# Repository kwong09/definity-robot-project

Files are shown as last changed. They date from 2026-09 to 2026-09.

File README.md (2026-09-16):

# definity-robot-project
## Project Description
A robot that navigates through a challenging obstacle course and can intake and shoot tennis balls. This project focuses on the frame of the robot and the intake subsystem (the rest of the team members worked on other parts of the robot!)

## Features:
* Intake system that can hold up to 8 tennis balls
* Robot frame with rotating front as suspension
* Drivebase that can run over cinderblocks and bricks

## CAD Model:
This is the full assembly of the robot with the intake subsystem attached.
The intake subsystem was tightened using M4 or M3 screws (either worked for the 3d printed shaft collars).
The Maxynos motors were attached to the frame of the robot using M3 screws.
The frame for the intake was made of Aluminum 6061 and was bent in the machine shop (drawings for the intake subsystem and frame for the robot are attached in the repository).  

When assembling the intake, start from the side that does not have the motor. Make sure to also add the belts on before pushing it through the bearing. That way, you are able to daisy chain the belts so that it alternates. Preview the picture of the actual assembly at the bottom of this readme file to see how you must orient the belts.



## More Photos and Videos!!
https://github.com/user-attachments/assets/d4b2ccb0-fa03-435b-ad92-068b4372a665



## Important Links
 - [Onshape document](https://cad.onshape.com/documents/242f1b4dc737510c4a5df910/w/1bdbd6909af1f2f738e34575/e/52617dcb231c25f66da39c03) *(this includes all the 3D print files as well as full robot assembly)*
 - [Parts list](https://docs.google.com/spreadsheets/d/1HUPfm7-IXxoTsjJXf8ZeQtVRJgV2OwNiN3OtU4khO2M/edit?usp=sharing) *(this has all of the parts that we bought off Amazon, AndyMark, etc. for any components we did not manufacture ourselves)*

## Bill of Materials (COTS Parts)
| Item | Link | Cost | Quantity | Total Cost | Notes |
| --- | --- | --- | --- | --- | --- |
| Motors | [Amazon.com: Maxynos Thor 2826 Planetary Gear Brushless Motor (Outrunner), DC 15 V, 3.7 N·m (37.7 kg·cm) Torque, 28 mm Gearbox, 6 mm Shaft, for Robotics, Automation, and RC Applications (1000KV, Gear Ratio 19:1) : Industrial & Scientific](https://www.amazon.com/dp/B0FL7X27B4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) | $57.99 | 5 | $289.95 | |
| ESC | [Amazon.com: 30A Electric Brushless Motor Controller, 2 Pcs ESC Speed Controller with XT60 and 3.5mm Bullet Plugs for RC Drone RC Airplane Helicopter (30A) : Toys & Games](https://www.amazon.com/Electric-Brushless-Controller-Airplane-Helicopter/dp/B0CZNM4H7H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) | $18.59 | 2 | $37.18 | not using anymore (unidirectional) |
| Wheel Rubber | [Amazon.com: TORRAMI Solid Neoprene Rubber Strips Roll 1/8 (.125) inch Thick X 2 inch Wide X 10 Feet, for DIY Weather Stripping, Gasket, Seal : Industrial & Scientific](https://www.amazon.com/Neoprene-Rubber-Strips-Weather-Stripping/dp/B0859FZR2S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) | $14.38 | 1 | $14.38 | |
| Battery | Other Team | $40.00 | 2 | $80.00 | |
| Charger | Other Team | $60.00 | 1 | $60.00 | |
| Screws | [https://www.amazon.com/smseace-Assortment-Machinery-Automotive-Motorcycle/dp/B0DN1676NW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](https://www.amazon.com/smseace-Assortment-Machinery-Automotive-Motorcycle/dp/B0DN1676NW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) | $7.99  | 1 | $7.99 | |
| Pillow bearings | [pson 2Pcs 25mm Bore Mounted Pillow Block Bearing KP000, Self‑Aligning Zinc Aluminum Alloy Housing for Linear Shaft Rods, Machinery: Amazon.com: Industrial & Scientific](https://www.amazon.com/pson-Mounted-Self%E2%80%91Aligning-Aluminum-Machinery/dp/B0G4D36Z1X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) | $6.69  | 1 | $6.69 | |
| Front Rotation Shaft | [McMaster-Carr](https://www.mcmaster.com/products/4138n85/) | $15.64 | 1 | $15.64 | |
| Front Rotation Collars | [McMaster-Carr](https://www.mcmaster.com/products/6056n18/) | $2.00  | 2 | $4.00 | |
| 1/8" Rivets | [McMaster-Carr](https://www.mcmaster.com/products/97447a020/) | $10.57 | 1 | $10.57 | |
| XT60 Power Distribution | [Amazon.com: XT60 to 4 Channel XT60 Plug Power Distribution Board Optional Base Shell for Robot RC Boat Submarine DIY Parts : Toys & Games](https://www.amazon.com/Channel-Power-Distribution-Optional-Submarine/dp/B0FQTJSRVB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) | $15.99 | 1 | $15.99 | |
| Rubber Glue | [https://www.amazon.com/dp/B0DLKMS6LR?niid=nl_cl_lst_a_1_0&ref_=nl_cl_lst_a_1_0&nrid=17TS82XMNZMFRY1FD6C7&th=1](https://www.amazon.com/dp/B0DLKMS6LR?niid=nl_cl_lst_a_1_0&ref_=nl_cl_lst_a_1_0&nrid=17TS82XMNZMFRY1FD6C7&th=1) | $7.99  | 1 | $7.99 | |
| ESC | [https://www.amazon.com/Maxynos-Bidirectional-Controller-Connector-Underwater/dp/B0FPWNBR88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](https://www.amazon.com/Maxynos-Bidirectional-Controller-Connector-Underwater/dp/B0FPWNBR88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) | $28.99 | 4 | $115.96 | bidirectional replacements |
| Double Sided Tape | [Amazon.com: tapify Double Sided Tape Heavy Duty 0.39 x 10FT \| Double Sided mounting Tape for Walls,vhb Strong for Car, LED Strip Light, Home/Office Decorr : Office Products](https://www.amazon.com/dp/B0CPX8HFNZ?psc=1&smid=A2Z15M95UG8Y2&ref_=chk_typ_imgToDp) | $6.99  | 1 | $6.99 | |
| EC3 to XT60 adapter | [Amazon.com: Laisomeke XT60 to EC3 Male Female Adapter Connector with 5CM Cable for RC FPV Drone Car Lipo NiMH Battery Charger ESC (4 Pack) : Toys & Games](https://www.amazon.com/gp/product/B0BY8RH35S/ref=ox_sc_act_title_2?smid=A16DPPR9USB1X5&psc=1) | $8.59  | 0.5 | $4.30 | |
| Wheel Hubs | [4Pcs 6mm Flange Coupling Connector, Rigid Guide Model Coupler Accessory, Shaft Axis Fittings for DIY RC Model Motors: Amazon.com: Industrial & Scientific](https://www.amazon.com/dp/B08334N261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) | $7.95  | 1 | $7.95 | |
| Buck Boosters | [Amazon.com: PlusRoc Waterproof 12V/24V to 5V 5A Step Down Converter, 25W DC-DC Buck Converter with Open Wires for DIY Electronics Projects (2-Pack) : Electronics](https://www.amazon.com/dp/B0FYNCSV2Z?psc=1&smid=A16MBAJLOTGB84&ref_=chk_typ_imgToDp) | $12.99 | 1 | $12.99 | |
| Pneumatic Wheels | [https://wcproducts.com/collections/wheels-hubs/products/pneumatic-wheels](https://wcproducts.com/collections/wheels-hubs/products/pneumatic-wheels) | $14.99 | 4 | $59.96 | Pneumatic Wheel Tire (8" OD, SmoothGrip) (WCP-0158) |
| IMU | [https://www.amazon.com/dp/B0CL26J81F](https://www.amazon.com/dp/B0CL26J81F) | $20.99 | 1 | $20.99 | |
| 12V Regulator | [https://www.amazon.com/dp/B07KWX33X5?niid=nl_cl_lst_a_1_2&ref_=nl_cl_lst_a_1_2&nrid=EKRBPCA692ZRFPZ2Z127&th=1](https://www.amazon.com/dp/B07KWX33X5?niid=nl_cl_lst_a_1_2&ref_=nl_cl_lst_a_1_2&nrid=EKRBPCA692ZRFPZ2Z127&th=1) | $14.99 | 1 | $14.99 | |
| 1/2" Hex Bearing | [https://www.amazon.com/XiKe-Bearing-Wheelbarrows-Suitable-Replacement/dp/B01MF5A4GF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](https://www.amazon.com/XiKe-Bearing-Wheelbarrows-Suitable-Replacement/dp/B01MF5A4GF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) | $14.99 | 2 | $29.98 | |
| 1/2" Hex Shaft | [https://www.mcmaster.com/9063T31-9063T313/](https://www.mcmaster.com/9063T31-9063T313/) | $15.38 | 2 | $30.76 | |
| Higher Quality Hubs | [Amazon.com: MORFUM 4Pcs Black 6mm Flange Coupling Connector, Aluminum Alloy Rigid Flange Coupling Motor Guide Shaft Coupler Shaft Axis Fittings Universal Aluminum Mounting Hub for 6mm Shaft : Industrial & Scientific](https://www.amazon.com/gp/product/B0FJ8DP4BY/ref=ox_sc_act_image_2?smid=A1Q5NIBUBLYOMT&psc=1) | $10.99 | 1 | $10.99 | |
| Pivot Motor Test | [Amazon.com: Copkim 6 Pack 12v DC Worm Gear Motor Turbine Electric Gear Box Motor with 8mm Flange Coupling Connector Rigid Flange Coupling and 370 Mounting Bracket with Screw for DIY Projects(12V 16rpm) : Industrial & Scientific](https://www.amazon.com/Copkim-Electric-Coupling-Connector-Mounting/dp/B0G2BNVRV7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) | $27.99 | 3 | $83.97 | |
| Flywheel motors | [Amazon.com: FairySandy 4 Pack 12V-24V 775 DC Electric Motor and GT2 Synchronous Wheel Aluminum Timing Pulley and DC Motor Speed Controller Driver Control Module for Milling Machine Electric Drill(D-Shaped Shaft) : Toys & Games](https://www.amazon.com/FairySandy-Electric-Synchronous-Aluminum-Controller/dp/B0FYFWTY6M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) | $16.99 | 2 | $33.98 | |
| Belt | [https://www.amazon.com/dp/B0FRDL4X1Z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](https://www.amazon.com/dp/B0FRDL4X1Z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) | $7.69  | 2 | $15.38 | 200mm L, 6mm W |
| PWM Relay Module | [https://www.amazon.com/ZORZA-Controller-Spotlight-Electronic-Airplane/dp/B0F1SHNWZR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](https://www.amazon.com/ZORZA-Controller-Spotlight-Electronic-Airplane/dp/B0F1SHNWZR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) | $13.99 | 1 | $13.99 | |
| Bidirectional Motor Driver | [hiBCTR 2-Piece Set of BTS7960 43A High-Power Motor Driver Modules, Ideal for Arduino with Current Limiting Function and Suitable as Smart Car Driver Modules - Amazon.com](https://www.amazon.com/gp/product/B0DXKXKYRK/ref=ox_sc_act_title_1?smid=ABNC1ZV0O9ATN&psc=1) | $15.09 | 1 | $15.09 | |
| 5mm Belt Pulley Flywheel | [Zeberoxyz 2PCS Set GT2 Synchronous Wheel 20&60 Teeth 5mm Bore Aluminum Timing Pulleys with 2PCS Length 200mm Width 6mm Belt (20-60T-5B-6): Amazon.com: Industrial & Scientific](https://www.amazon.com/gp/product/B08QYYF6W4/ref=sw_img_1?smid=&th=1) | $12.24 | 1 | $12.24 | |
| Flywheel Bearings | [Amazon.com: (4-Pack) 5/8" Bearings Carbon Steel - ID 5/8" x OD 1-3/8" Applicable Lawn Mower, Wheelbarrows, Carts and Hand Trucks Wheel Bearings Replacement : Patio, Lawn & Garden](https://www.amazon.com/gp/product/B0CFDP4YVD/ref=ox_sc_act_title_1?smid=A330SW4YE3KV7X&th=1) | $6.64  | 1 | $6.64 | |
| Pivot Pillow Bearings | [4Pcs KFL08 Pillow Block Bearing 8mm Bore Flanged Ball Mounted Bearing Block \| Zinc Alloy Insert Bearing Self-Alignment: Amazon.com: Industrial & Scientific](https://www.amazon.com/gp/product/B07K6B8M4P/ref=ox_sc_act_title_2?smid=A1M8G92U41XEUX&psc=1) | $6.65  | 1 | $6.65 | |
| 8mm Pivot Shaft | [https://www.amazon.com/gp/product/B0D5D3KFQX/ref=ox_sc_act_title_3?smid=A1MDC9YLETZE7Z&psc=1](https://www.amazon.com/gp/product/B0D5D3KFQX/ref=ox_sc_act_title_3?smid=A1MDC9YLETZE7Z&psc=1) | $6.49  | 1 | $6.49 | |
| PLA | [Amazon.com: Bambu Lab PLA Basic (1.75mm, 1kg) Refill : Industrial & Scientific](https://www.amazon.com/gp/product/B0CF612DH7/ref=ox_sc_act_image_1?smid=A1HNA4NM4KNLEO&psc=1) | $24.00 | 1 | $24.00 | |
| Intake motor | [https://www.amazon.com/gp/product/B07XPCKHRM/ref=ox_sc_act_title_1?smid=AC5VH8O1DV1ER&psc=1](https://www.amazon.com/gp/product/B07XPCKHRM/ref=ox_sc_act_title_1?smid=AC5VH8O1DV1ER&psc=1) | $14.49 | 1 | $14.49 | |
| HTD-5M Belts | [https://www.amazon.com/dp/B0DZ6LSYND/ref=twister_B0DYDBK3M9?_encoding=UTF8&psc=1](https://www.amazon.com/dp/B0DZ6LSYND/ref=twister_B0DYDBK3M9?_encoding=UTF8&psc=1) | $11.87 | 3 | $35.61 | 220 mm circumference |
| Flywheels + Shipping | [2" OD x 1/2" Wide Straight Flex Wheel (1/2" Hex Stretch, 45A) – WestCoast Products](https://wcproducts.com/products/wcp-1285?variant=44232622342356) | $28.09 | 1 | $28.09 | |
| 2D Lidar | [Amazon.com: WayPonDEV FHL-LD19 360 Degree 2D Lidar Distance Sensor Kit, 10Hz Scan Rate and 12m Distance Lidar Scanner Module for Smart Obstacle/Robot/Maker Education Indoor/Outdoor : Industrial & Scientific](https://www.amazon.com/DTOF-D300-Distance-Obstacle-Education/dp/B0B1V8D36H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) | $68.99 | 1 | $68.99 | |
| Conveyor Rubber | [Amazon.com: TORRAMI Solid Neoprene Rubber Strips Roll 1/8 (.125) inch Thick X 2 inch Wide X 10 Feet, for DIY Weather Stripping, Gasket, Seal : Industrial & Scientific](https://www.amazon.com/Neoprene-Rubber-Strips-Weather-Stripping/dp/B0859FZR2S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) | $14.38 | 1 | $14.38 | |
| Intake Arm Servo | [Amazon.com: ZOSKAY Servo High Torque Metal Gear Standard Digital Servo 25KG/0.13S 6.8V for 1/8 1/10 RC Cars (Control Angle 180) : Toys & Games](https://www.amazon.com/gp/product/B07GLMDJQ7/ref=ox_sc_act_title_2?smid=A1L550QEP2LVNB&th=1) | $17.99 | 1 | $17.99 | |
| Subtotal | | | | $1,264.22  | |

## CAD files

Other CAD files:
cad/full robot with intake.step

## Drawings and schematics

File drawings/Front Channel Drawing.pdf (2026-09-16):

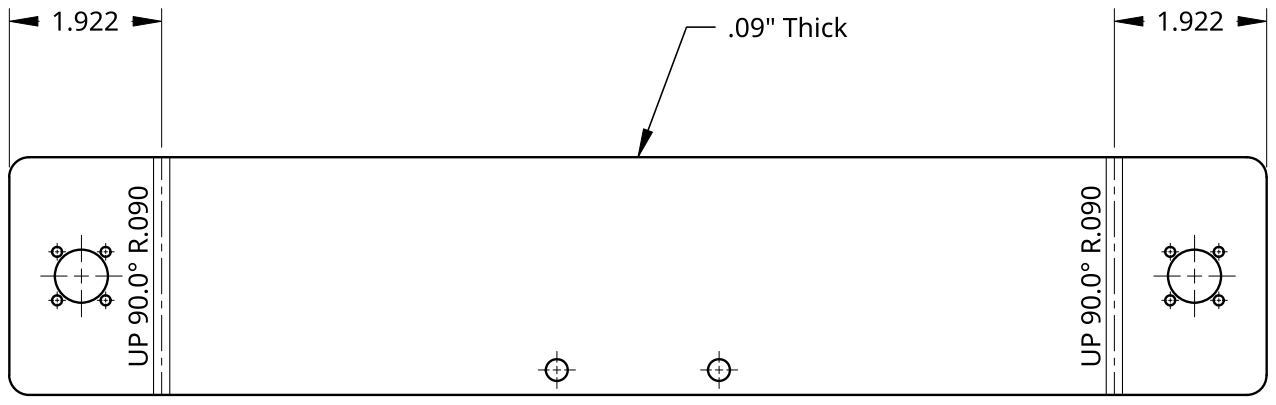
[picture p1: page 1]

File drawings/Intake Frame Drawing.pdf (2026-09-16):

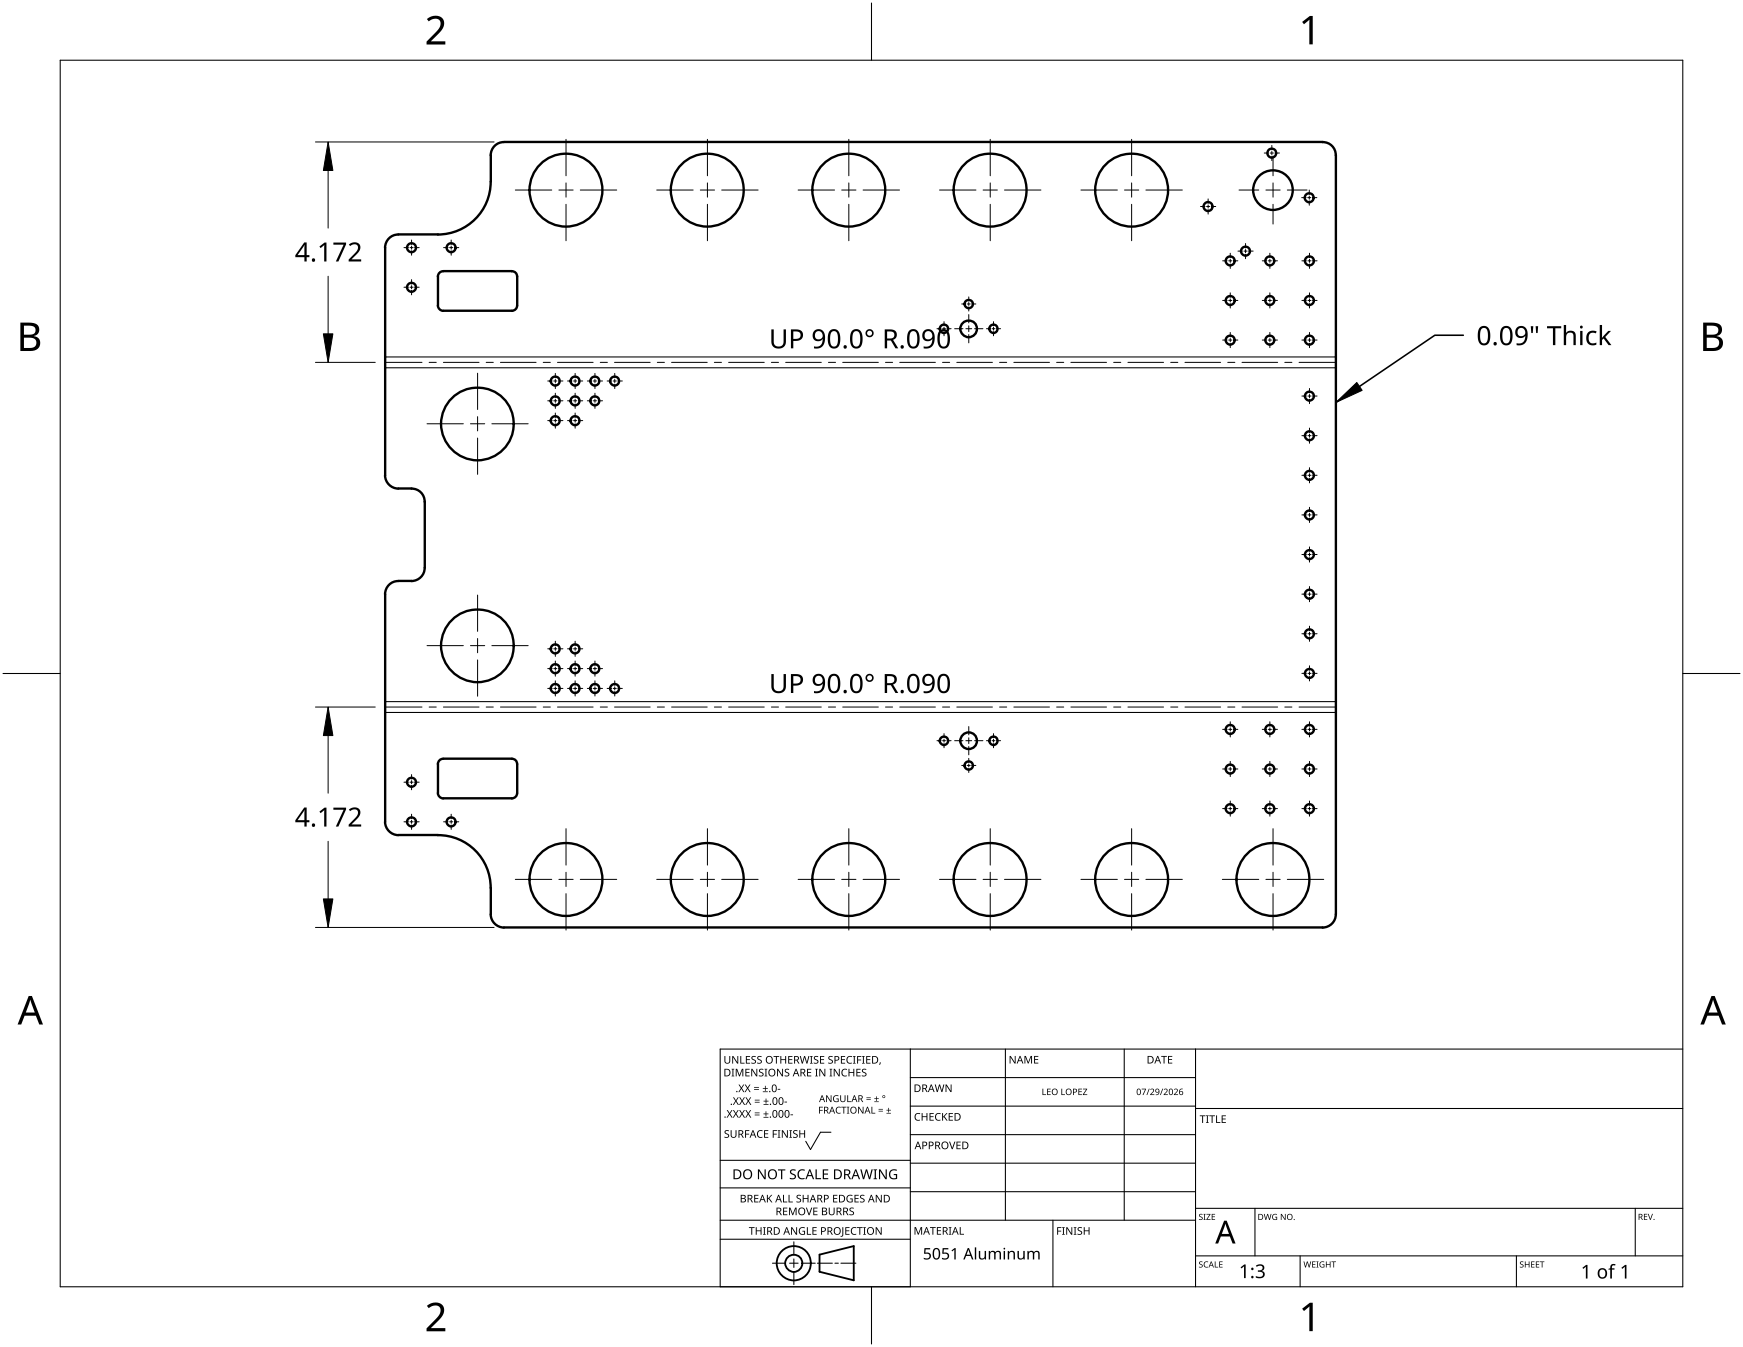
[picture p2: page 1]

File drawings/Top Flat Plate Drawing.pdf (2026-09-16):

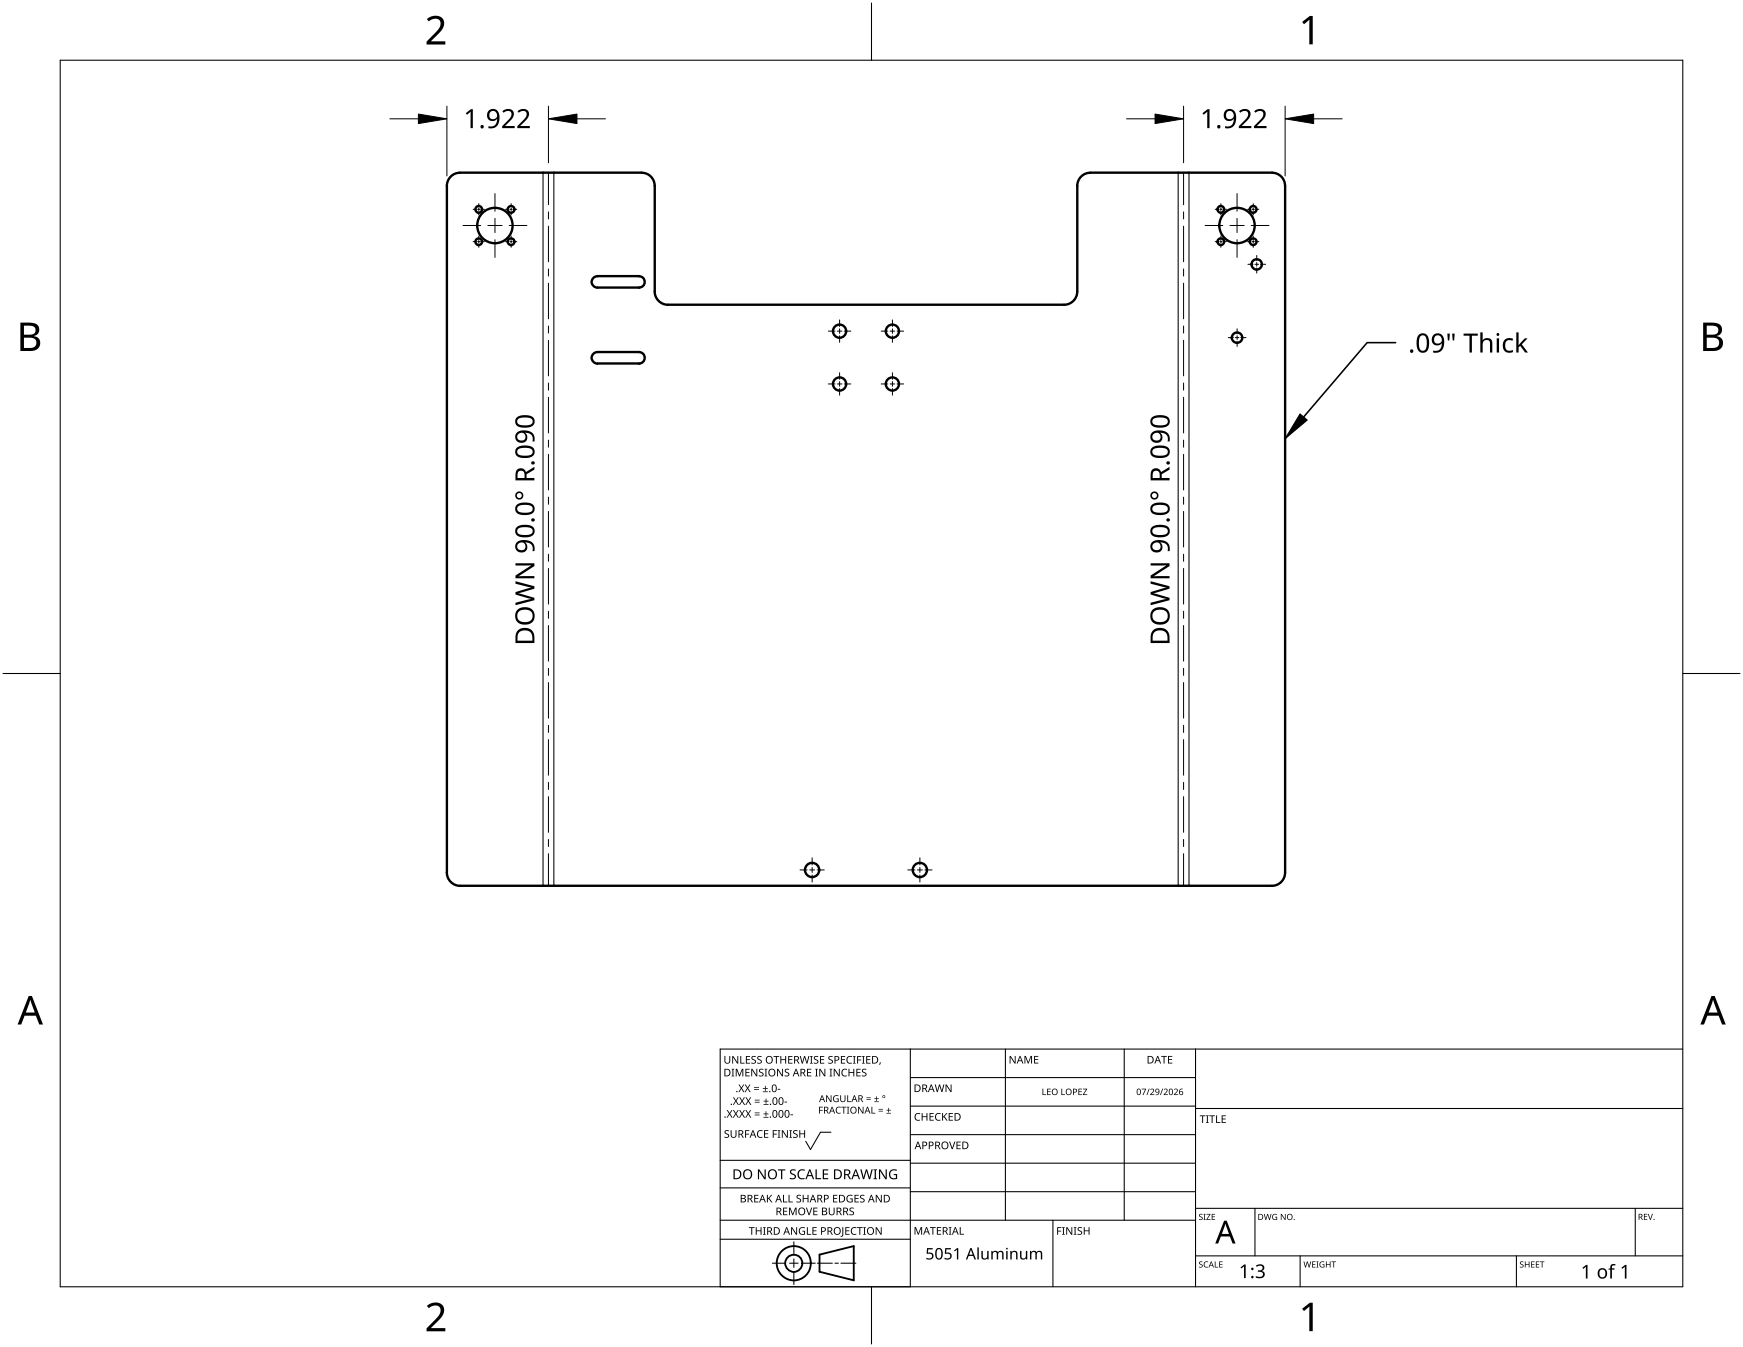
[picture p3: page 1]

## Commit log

2026-09-16 Rename Intake Frame Drawing.pdf to drawings/Intake Frame Drawing.pdf
2026-09-16 Rename Top Flat Plate Drawing.pdf to drawings/Top Flat Plate Drawing.pdf
2026-09-16 Rename full robot with intake.step to cad/full robot with intake.step
    [full robot with intake.step]
